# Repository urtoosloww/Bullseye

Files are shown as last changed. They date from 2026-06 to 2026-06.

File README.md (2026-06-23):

# Bullseye

A Raspberry Pi 5 desktop turret that detects a human hand with a real neural network,
rotates a servo to center it in frame, locks on with red targeting eyes, fires a
visible laser, and plays a custom voice/laser sound sequence.

---

## Why I built this

I built Bullseye because I wanted to test my 3D modeling skills and grow as a hardware
creator. I thought turrets were cool, and I wanted a project that combined CAD, embedded
electronics, computer vision, and audio into one build I could actually demo.

---

## What it does (the sequence)

1. Sits idle, scanning slowly side to side, white eyes searching.
2. Sees your hand → eyes pop alert, "I see you" plays.
3. Servo rotates to center your hand in frame.
4. When centered → LOCK: eyes turn red and pulsing, laser turns on, voice line
   "I've got you in my sights" plays followed by a laser firing sound.
5. While the audio plays, the whole robot freezes - servo silent, eyes locked red.
6. When the audio finishes, normal tracking resumes. Move far away to break the lock.

---

## Hardware

- Raspberry Pi 5 (with the official 27 W USB-C supply recommended)
- USB webcam (any UVC class - I used a GEMBIRD "W1")
- USB-powered speaker (plug-and-play)
- **SG90 hobby servo** - mounted as the yaw base under the head. It's small,
  cheap, and has just enough torque for a light 3D-printed head. If you make
  the head heavy, counterweight the back, or swap to an MG996R.
- ILI9341 3.2" SPI LCD (320x240)
- Laser diode module (3-pin: VCC / GND / signal)
- **Momentary push button** - wired to GPIO26 and GND. Used for BOTH safe
  shutdown AND boot, no terminal needed. See assembly steps below.
- ~1000 µF capacitor across servo power+ground recommended for stability
- Jumper wires
- 3D-printed chassis (see cad/ for files)

---

## Wiring

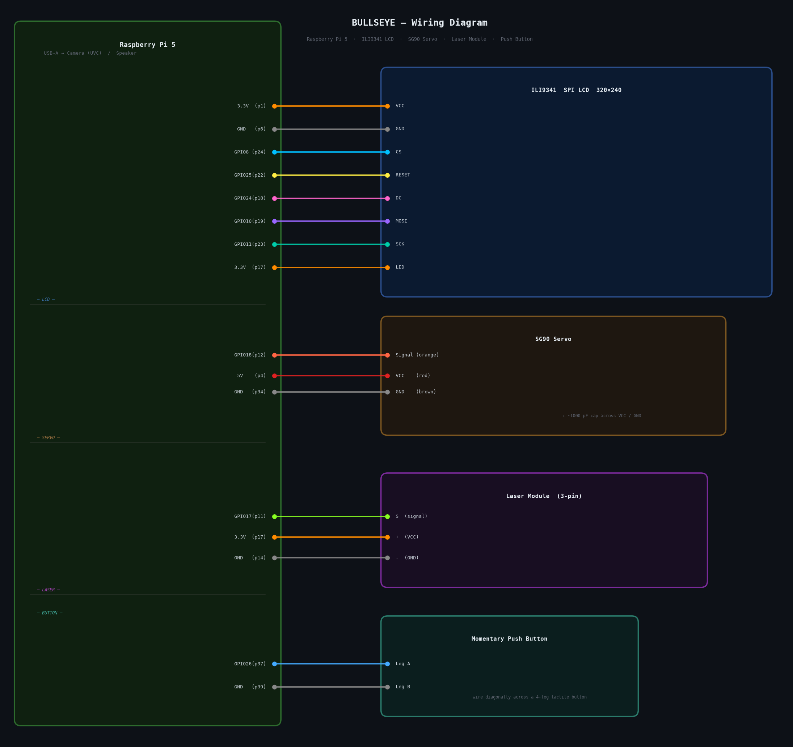
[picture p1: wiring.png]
Wiring Diagram


See the diagram above for all connections. Common-ground note: if you ever power the servo from an external 5 V supply, bridge its GND to any Pi GND pin or signals will float.

### LCD (ILI9341, SPI) - 8 wires, no touch panel used

| LCD pin | Pi pin |
|---|---|
| VCC | 3.3 V (pin 1) |
| GND | GND (pin 6) |
| CS | GPIO8 (pin 24) |
| RESET | GPIO25 (pin 22)  |
| DC | GPIO24 (pin 18)  |
| MOSI | GPIO10 (pin 19)  |
| SCK | GPIO11 (pin 23)  |
| LED | 3.3 V (pin 17) |

### Servo (SG90)

| Wire (colour) | Goes to |
|---|---|
| Signal (orange) | GPIO18 (pin 12) - hardware PWM channel 2 |
| Power (red) | 5 V (Pi pin 2/4, with cap if available)  |
| Ground (brown)  | GND (any Pi GND pin) |

### Laser module (3-pin)

| Laser pin | Goes to |
|---|---|
| + (VCC) | 3.3 V or 5 V on Pi |
| - (GND) | GND on Pi |
| S (signal)| GPIO17 (pin 11) |

### Shutdown / boot button

- One leg to GPIO26 (pin 37)
- Other leg to GND (pin 39)

### USB ports

USB camera and USB speaker plugged directly into the Pi.

---

## Assembly Guide

This is what I did to physically put Bullseye together. Read the wiring tables first.

### Step 1 - Print the chassis

Print all parts from cad/. The chassis is two main pieces:
- A fixed **BASE** that holds the Pi, the wiring, and bolts the servo down.
- A rotating **HEAD** that mounts on the SG90's horn and carries the LCD, camera,
  and laser, all pointing forward.

### Step 2 - Mount the SG90 servo into the base

The SG90 is what makes the robot pan left and right (it has NO up/down axis -
that's intentional; the pupils on the LCD handle vertical movement).

- Drop the servo into the slot in the base so the shaft points straight up.
- Screw it down firmly through the SG90's mounting flanges. The body must NOT
  move; only the horn on top should rotate.
- Pick a horn from the SG90's accessory bag. Press it onto the spline lightly
  (don't push it on hard yet - we'll align it).

### Step 3 - Mount the head onto the servo horn

- Screw or hot-glue the chosen horn into the pocket on the underside of the head.
- Now place the head onto the SG90 spline so it's roughly facing forward when
  the servo is at its center.
- Once aligned, secure the horn with the small screw that came with the SG90
  (in the accessory bag) - this is what stops the head popping off when it spins.
  Almost everyone forgets this screw. Don't.

### Step 4 - Mount the camera, LCD, and laser on the head

All three go on the FRONT of the head, facing forward:
- LCD in its frame slot (eyes facing out).
- Camera mounted above or beside the LCD, pointing forward.
- Laser screwed in next to the camera so its dot lands near the center of
  what the camera sees. Eyeball this - you can sight it later by running
  `laser_test.py` and adjusting until the dot is centered in the camera feed.

### Step 5 - Run the wires through the head into the base

Bundle the LCD ribbon + camera USB + laser wires together and route them down
past the servo shaft into the base. **Leave a loose loop of slack** so the
head can pan a full ~140 degrees without pulling on the cables. Tight cables
will fight the servo and burn it out.

### Step 6 - Wire to the Pi (per the wiring tables above)

Connect the LCD, servo, laser, and shutdown button to the Pi's GPIO pins.
USB camera and USB speaker go into Pi USB ports.

### Step 7 - Install and wire the power button

This is the cleanest part of the build - you never have to type a shutdown
command or yank power again.

- Pick a momentary push button (the four-leg tactile kind is fine).
- Drill or print a hole in the side of the base where you want the button.
- Wire one leg of the button to **GPIO26 (physical pin 37)** on the Pi.
- Wire any leg on the OTHER side of the button to a **GND pin** (pin 39 is
  right next to GPIO26 and convenient).
- IMPORTANT: on a 4-leg tactile button, the two legs on the same side are
  permanently connected. You must wire across the gap (diagonal), not two
  legs on the same side.

How the button works once configured:
- **Pi is OFF → press button → Pi boots up** (and Bullseye starts on its own
  via the systemd user service). This is a built-in GPIO26 hardware feature.
- **Pi is RUNNING → press button → clean kernel shutdown**, triggered by the
  `dtoverlay=gpio-shutdown,gpio_pin=26` line in config.txt. Wait for the
  green LED to stop blinking, then it's safe to cut power.

Result: power flow becomes "press to turn on, press to turn off." No SSH,
no keyboard, no risk of SD card corruption from yanked power.

### Step 8 - Balance the head

The LCD + camera + laser all sit on the front of the head, so the head is
front-heavy by default. If the SG90 strains, hums, or droops:
- Tape a counterweight (coins, a small bolt, etc.) to the BACK of the head
  behind the servo shaft until it sits roughly level.
- The code already auto-relaxes the servo between moves to ease the load,
  but mechanical balance is still the best fix.

---

## /boot/firmware/config.txt additions

Add these lines (the project depends on each):

```
dtparam=spi=off
dtoverlay=spi0-0cs
dtoverlay=pwm
dtoverlay=gpio-shutdown,gpio_pin=26
usb_max_current_enable=1
```

---

## /boot/firmware/cmdline.txt additions

Append this to the existing single line (with a space before it). It tells usb-storage
to ignore the webcam, which on some cheap cams claims interface 0 and blocks uvcvideo
from binding. Replace `1908:1331` with your camera's `lsusb` ID if different.

```
usb-storage.quirks=1908:1331:i
```

---

## System dependencies

```bash
sudo apt update
sudo apt full-upgrade -y
sudo apt install -y python3-opencv python3-lgpio python3-gpiozero python3-pil \
                    python3-numpy mpv mpg123 v4l-utils ffmpeg
```

---

## Python dependencies

```bash
pip install onnxruntime adafruit-circuitpython-rgb-display adafruit-blinka \
            rpi-hardware-pwm --break-system-packages
```

---

## Project layout

Place all the files in `/home/<user>/` (the scripts read paths relative to themselves):

```
/home/<user>/ai_robot_boot.py
/home/<user>/vision_debug.py
/home/<user>/servo_test.py
/home/<user>/laser_test.py
/home/<user>/palm_detection.onnx
/home/<user>/audio/detect.mp3
/home/<user>/audio/lockon_seq.mp3
```

---

## First-run tests (do these BEFORE running the robot)

1. Test the servo on its own:
   ```bash
   python3 servo_test.py
   ```

2. Test the laser on its own:
   ```bash
   python3 laser_test.py
   ```

3. Test the LCD and detector together (live view, needs monitor):
   ```bash
   python3 vision_debug.py
   ```

4. Run the full robot:
   ```bash
   python3 ai_robot_boot.py
   ```

---

## Run on boot (headless, no keyboard/monitor/mouse)

Copy the service file, enable lingering, and enable + start the service:

```bash
mkdir -p ~/.config/systemd/user
cp systemd/airobot.service ~/.config/systemd/user/airobot.service
loginctl enable-linger $USER
systemctl --user daemon-reload
systemctl --user enable airobot.service
systemctl --user start airobot.service
journalctl --user -u airobot.service -f    # live logs
```

To stop / disable:

```bash
systemctl --user stop airobot.service
systemctl --user disable airobot.service
```

---

## Power button behavior

Wired button shorts GPIO26 to GND momentarily.
- Pi off, press button → boots up, robot auto-starts.
- Pi on, press button → kernel does a clean shutdown.

---

## Troubleshooting (from real debugging during the build)

- **Camera detected by lsusb but no /dev/videoN**: usb-storage is claiming it.
  The cmdline.txt quirk above fixes this. After editing, `sudo reboot`.

- **Camera drops after running a while**: USB power. Use the official 27 W Pi 5 supply,
  add `usb_max_current_enable=1`, or put the camera on a powered USB hub.

- **Servo buzzing/ringing after a few seconds**: it's straining against a top-heavy load.
  Counterweight the back of the body, or the code already auto-relaxes the servo
  between moves to reduce this.

- **"GPIO busy"**: the service or an old run is still holding the pin.
  ```bash
  systemctl --user stop airobot.service && pkill -f ai_robot_boot.py
  ```

---

## CAD

Files in `cad/` are FDM-printable. Mount the head (LCD + camera + laser) on the SG90's
horn; bolt the SG90 body into the base; keep the camera and laser aligned forward so
the laser dot lands inside the camera frame.

---

## Credits

Neural detector: MediaPipe Palm Detection (ONNX export by PINTO0309).

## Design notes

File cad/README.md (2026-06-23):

# CAD Files

This folder contains the 3D model files for the Bullseye chassis.

## Files

| File | Format | Description |
|---|---|---|
| CAD model.f3d | Fusion 360 | Full assembly - base + rotating head |

## Printing

All structural parts are designed for **FDM printing** (PLA or PETG recommended).

- **Base** - holds the Raspberry Pi, wiring, and servo body. Print with 20%+ infill.
- **Head** - mounts on the SG90 horn and carries the LCD, camera, and laser on the front face. Keep it as light as possible to reduce servo strain.

## Tips

- Export individual bodies from the F3D as STLs before slicing.
- The servo slot in the base is sized for a standard SG90 footprint - do not scale the model or it will not fit.
- Leave a loop of wire slack when routing cables through the head so the full ~140 degree pan range is free.

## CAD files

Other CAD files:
cad/CAD model.f3d

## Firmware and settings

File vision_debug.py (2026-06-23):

#!/usr/bin/env python3
"""
Vision debug v3 - NEURAL hand detection (run on the desktop)
============================================================
Shows what the neural detector sees:
  GREEN box + score = confident hand detection (what the robot tracks)
  GRAY  box + score = seen but below the confidence slider

Slider: min score % - confidence required. Raise if any false positives.
'q' to quit.   No calibration exists anymore - none is needed.
"""
import cv2, numpy as np, os
import onnxruntime as ort

HERE = os.path.dirname(os.path.abspath(__file__))
sess = ort.InferenceSession(os.path.join(HERE, "palm_detection.onnx"),
                            providers=["CPUExecutionProvider"])
IN_NAME = sess.get_inputs()[0].name
print("neural palm detector loaded")

def open_cam():
    for idx in [0, 1, 2, 3]:
        c = cv2.VideoCapture(idx, cv2.CAP_V4L2)
        if c.isOpened():
            c.set(cv2.CAP_PROP_FOURCC, cv2.VideoWriter_fourcc(*'MJPG'))
            c.set(cv2.CAP_PROP_FRAME_WIDTH, 640)
            c.set(cv2.CAP_PROP_FRAME_HEIGHT, 480)
            ok, _ = c.read()
            if ok:
                print(f"camera at /dev/video{idx}"); return c
        c.release()
    return None

cap = open_cam()
if cap is None:
    print("no camera found"); raise SystemExit(1)

cv2.namedWindow("Debug")
def _n(x): pass
cv2.createTrackbar("min score %", "Debug", 55, 95, _n)

while True:
    ok, frame = cap.read()
    if not ok:
        print("camera fail"); break
    frame = cv2.flip(frame, 1)
    h, w = frame.shape[:2]
    min_score = max(5, cv2.getTrackbarPos("min score %", "Debug")) / 100.0

    img = cv2.resize(frame, (192, 192))
    img = cv2.cvtColor(img, cv2.COLOR_BGR2RGB)
    inp = (img.astype(np.float32) / 255.0)[None].transpose(0, 3, 1, 2)
    rows = sess.run(None, {IN_NAME: inp})[0]

    found = False
    for r in rows:
        score, bx, by, bs = float(r[0]), float(r[1]), float(r[2]), float(r[3])
        if score < 0.30:
            continue
        cx_, cy_ = int(bx * w), int(by * h)
        half = int(bs * max(w, h) / 2)
        good = score >= min_score
        color = (0, 255, 0) if good else (160, 160, 160)
        cv2.rectangle(frame, (cx_-half, cy_-half), (cx_+half, cy_+half), color, 2)
        cv2.putText(frame, f"{score:.2f}", (cx_-half, cy_-half-6),
                    cv2.FONT_HERSHEY_SIMPLEX, 0.6, color, 2)
        if good: found = True

    lbl, lc = ("HAND DETECTED", (0,255,0)) if found else ("nothing", (0,0,255))
    cv2.putText(frame, lbl, (10, 25), cv2.FONT_HERSHEY_SIMPLEX, 0.7, lc, 2)
    cv2.imshow("Debug", frame)
    if cv2.waitKey(1) & 0xFF == ord('q'):
        break

cap.release()
cv2.destroyAllWindows()

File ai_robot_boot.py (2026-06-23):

#!/usr/bin/env python3
"""
AI Tracking Robot - HEADLESS (Raspberry Pi 5)   [neural detection]
==================================================================
- Neural hand detection (ONNX palm detector) - no calibration
- Servo (GPIO18 hardware PWM) actively centers the target; structured
  scan-sweep when the target is lost
- LCD eyes track smoothly (NO blinking); red targeting state holds
- Lock-on plays one seamless sound (voice + laser merged)

Files needed here: palm_detection.onnx, detect.mp3, lockon_seq.mp3
Install once: pip install onnxruntime --break-system-packages
"""
import cv2, numpy as np, os, threading, time, math, signal, subprocess, shutil
import onnxruntime as ort
from rpi_hardware_pwm import HardwarePWM
from gpiozero import LED
import board, digitalio
from adafruit_rgb_display import ili9341
from PIL import Image, ImageDraw

HERE        = os.path.dirname(os.path.abspath(__file__))
MODEL_FILE  = os.path.join(HERE, "palm_detection.onnx")
DETECT_FILE = os.path.join(HERE, "detect.mp3")        # "I see you" on first sight
SEQ_FILE    = os.path.join(HERE, "lockon_seq.mp3")    # voice + laser, merged

MIN_SCORE = 0.55      # detection confidence (raise = stricter)

# ---------------- neural detector ----------------
sess = ort.InferenceSession(MODEL_FILE, providers=["CPUExecutionProvider"])
IN_NAME = sess.get_inputs()[0].name
print("Neural palm detector loaded", flush=True)

def detect_hand(frame):
    h, w = frame.shape[:2]
    img = cv2.resize(frame, (192, 192))
    img = cv2.cvtColor(img, cv2.COLOR_BGR2RGB)
    inp = (img.astype(np.float32) / 255.0)[None].transpose(0, 3, 1, 2)
    rows = sess.run(None, {IN_NAME: inp})[0]
    if rows.shape[0] == 0:
        return None
    best = rows[np.argmax(rows[:, 0])]
    score, bx, by, bs = float(best[0]), float(best[1]), float(best[2]), float(best[3])
    if score < MIN_SCORE:
        return None
    return (int(bx * w), int(by * h), int(bs * max(w, h)))

# ---------------- shared state ----------------
state_lock = threading.Lock()
shared = {"locked": False, "hx": 0.0, "hy": 0.0, "running": True}
def clamp(v, lo, hi): return max(lo, min(hi, v))

# ---------------- servo + laser ----------------
servo_pwm = HardwarePWM(pwm_channel=2, hz=50)
servo_pwm.start(0)
def set_angle(a):
    a = clamp(a, 0, 180)
    servo_pwm.change_duty_cycle(2.5 + a / 18.0)
laser = LED(17)

# ---------------- sound (only ONE clip can play at a time) ----------------
_PLAYER = (["mpv", "--no-video", "--really-quiet"] if shutil.which("mpv")
           else ["mpg123", "-q"])
audio_lock  = threading.Lock()
current_proc = None
current_is_lockon = False        # True only while the lockon sequence is playing

def play_audio(path, interrupt=False):
    """Plays a sound file. Enforces single-track audio:
       - if something is already playing and interrupt=False -> SKIP (no overlap)
       - if something is already playing and interrupt=True  -> stop it, play this one
    """
    global current_proc, current_is_lockon
    with audio_lock:
        if current_proc is not None and current_proc.poll() is None:
            if not interrupt:
                return
            current_proc.terminate()
            try: current_proc.wait(timeout=0.3)
            except Exception: pass
        if os.path.exists(path):
            current_proc = subprocess.Popen(
                _PLAYER + [path],
                stdout=subprocess.DEVNULL, stderr=subprocess.DEVNULL)
            current_is_lockon = (path == SEQ_FILE)

def lockon_is_playing():
    """True iff the lockon sequence audio is still playing right now."""
    global current_is_lockon
    with audio_lock:
        if not current_is_lockon:
            return False
        if current_proc is None or current_proc.poll() is not None:
            current_is_lockon = False
            return False
        return True

# ---------------- clean shutdown ----------------
def stop(*_):
    with state_lock:
        shared["running"] = False
signal.signal(signal.SIGTERM, stop)
signal.signal(signal.SIGINT, stop)

# ======================================================================
#  FACE THREAD - smooth tracking eyes, no blinking
# ======================================================================
def face_loop():
    cs_pin    = digitalio.DigitalInOut(board.CE0)
    dc_pin    = digitalio.DigitalInOut(board.D24)
    reset_pin = digitalio.DigitalInOut(board.D25)
    spi = board.SPI()
    disp = ili9341.ILI9341(spi, cs=cs_pin, dc=dc_pin, rst=reset_pin,
                           baudrate=24000000, rotation=90)
    W, H = (disp.height, disp.width) if disp.rotation % 180 == 90 else (disp.width, disp.height)
    eye_r, pupil_r = 55, 22
    travel = eye_r - pupil_r - 6
    cy = H // 2
    eye_cx = [W // 2 - 80, W // 2 + 80]
    mid_x = (eye_cx[0] + eye_cx[1]) // 2
    disp_hx = disp_hy = 0.0
    img = Image.new("RGB", (W, H)); draw = ImageDraw.Draw(img)

    while True:
        with state_lock:
            if not shared["running"]: break
            locked = shared["locked"]
            hx, hy = shared["hx"], shared["hy"]
        now = time.time()

        # smooth, intentional pupil motion (no blinking, no jitter)
        disp_hx += 0.22 * (hx - disp_hx)
        disp_hy += 0.22 * (hy - disp_hy)

        draw.rectangle((0, 0, W, H), fill=(0, 0, 0))

        if locked:
            pulse = 0.5 + 0.5 * math.sin(now * 8.0)
            inten = int(150 + 105 * pulse)
            red   = (inten, 0, 0)
            glow  = (int(inten * 0.30), 0, 0)
            for ex in eye_cx:
                draw.ellipse((ex-eye_r-12, cy-eye_r-12, ex+eye_r+12, cy+eye_r+12), fill=glow)
                draw.ellipse((ex-eye_r, cy-eye_r, ex+eye_r, cy+eye_r), fill=red)
                px = ex + disp_hx * (eye_r * 0.45)
                py = cy + disp_hy * (eye_r * 0.45)
                ring = int(13 + 4 * pulse)
                draw.ellipse((px-ring, py-ring, px+ring, py+ring), outline=(255,255,255), width=2)
                draw.line((px-ring-7, py, px+ring+7, py), fill=(255,255,255), width=2)
                draw.line((px, py-ring-7, px, py+ring+7), fill=(255,255,255), width=2)
                draw.ellipse((px-3, py-3, px+3, py+3), fill=(255,255,255))
                if ex < mid_x:
                    draw.line((ex-eye_r, cy-eye_r-16, ex+eye_r, cy-eye_r-1), fill=red, width=9)
                else:
                    draw.line((ex-eye_r, cy-eye_r-1, ex+eye_r, cy-eye_r-16), fill=red, width=9)
        else:
            for ex in eye_cx:
                draw.ellipse((ex-eye_r, cy-eye_r, ex+eye_r, cy+eye_r), fill=(255,255,255))
                px = ex + disp_hx * travel
                py = cy + disp_hy * travel
                draw.ellipse((px-pupil_r, py-pupil_r, px+pupil_r, py+pupil_r), fill=(20,20,20))

        disp.image(img); time.sleep(0.04)

    draw.rectangle((0, 0, W, H), fill=(0, 0, 0)); disp.image(img)
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

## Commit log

2026-06-23 Initial commit: Bullseye AI tracking turret
    Raspberry Pi 5 desktop turret with neural hand detection (MediaPipe palm ONNX),
    SG90 servo yaw, ILI9341 LCD eyes, laser diode, and audio lock-on sequence.
    Includes Python scripts, audio assets, Fusion 360 CAD model, systemd user
    service, wiring reference, and full README with assembly guide.
    [CAD model.f3d]
2026-06-23 Add visual wiring diagram (wiring.png)
    Generated with matplotlib: dark-theme PCB-style layout showing the Pi 5
    alongside the LCD, servo, laser, and button. Each connection is color-coded
    by signal (3.3V, 5V, GND, and one unique color per GPIO). README and
    wiring.md now embed the image directly.
2026-06-23 Fix wiring diagram: proper spacing between component boxes
    Servo was overlapping LCD, laser section label was bleeding into servo area.
    Rebuilt with explicit gap budgets: 0.7u LCD→Servo, 1.1u Servo→Laser, 0.9u Laser→Button.
    All wires are now perfectly horizontal (Pi pin y == component pin y).
2026-06-23 Remove wiring.md, drop legend from wiring diagram
    Single source of truth: wiring.png only. Removed the redundant ASCII
    markdown file and stripped the legend box from the diagram — connection
    labels on the wires themselves are sufficient.
